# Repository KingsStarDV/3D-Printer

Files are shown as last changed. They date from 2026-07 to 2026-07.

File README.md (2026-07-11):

# 3D Printer

So by this time, really everyone knows what a 3d printer is...

### WHy I build it?

SO i built it for fun mainly..
i was out of ideas for normal project thus i started this..

This would definelty help not just me but many other people too, to make their own 3D printer !!

### How I build it and How can You Build this

## Requirement:

* ALuminium Extrusions of-
  * 2020 size- 380mm x2
  * 400mm x2
  * 2040 size- 150mm x2
  * 420mm x1
* Corner Brackets x4
* Inner Joints x6
* Sliding Nuts [as per your need, read the instructions first for this]
* Hot Glue
* Bolts
* Nuts
* 2020 Gantry Plates x4
* Derlin V wheels x16
* Nema 17 Stepper Motor x4
* Nema 17 Mounting bracket (L shaped) x4
* GT2 20 teeth Pulley x2
* 10mm timing belt (open)
* 10mm Idler Pulley x5
* 5mm to 8mm Coupler x1
* Lead Screw Tr8x2 x1
* Arduino Mega x1
* Ramps 1.4 x1
* Stepper Driver x4
* Power Supply (12v)
* Endstop swichtes
* Zip Ties
* MK8 hot end
* MK8 extruder
* hot bed

## Assembly

First Of all attach the two 150mm 2040 extrusions to the sides of the 420mm 2040 extrusion.



Secure it with inner joints on all 4 corners-



Next add the two 400mm 2020 extrusion of each side of the 150mm extrusion end- **[NOTE- In the image, i have used 2040 extrusion but i will change that later on due to some reasons.. so dont worry and add the 2020 extrusion]**



secure it with corner joints-



Now asseble your all 4 gantry plates with the wheels-



Now put one gantry plate along the 420mm extrusion (This will be the Y axis).



now take 2 gantry plates and fix them at end of a 380mm 2020 aluminium extrusion.. [Now you can use either HOT GLUE or SLiding joints to do this--- i will use hot glue]
And then put the 4th gantry plate along the 380mm aluminium extrusion you just fixed..



Now at one end of the Y axis (420mm extrusion 2040) fix a nema 17 mount (with either hot glue or sliding joints), and then hot glue the nema 17 motor to it-



This is not the indented way of using the nema 17 mount, but it works !!



then add a GT2 20 teeth pullay to the motor and also add a 10mm Idler pulley as shown in image below..For idler pulley support, you can use any hard- wooden block or hard carboard piece-



Now on the other end of the Y axis- with wooden blocks or cardboard make this and add two idler pulley to it-



Then take one nema 17 mount and cut it and modify it as-



This will go on the x axis along with the stepper motors (This can be hot glued or if possibles, screwed into the gantry plate)-



Next, we will require another custom part-



this can be made easily with cardboard(for the base) and old pens(for the cyclinderical part).

It has to be glued at the other end of the X axis-





Now at the top of the two 400mm 2020 extrusions add another 380mm extrusion..
and then fix another nema 17 mount (via either sliding nuts or hot glue)

Then fix the stepper motor to it-



Add a 5mm to 8mm coupler to it-



Now with help of another custom part make this (add the trapezoidal nut)--



he part must be fixed to the x axis.

Then take your extruder and fix it on the 400mm 2020 extrusion-



And make another custom part-



USe this to fix the hot end-



**If done every thing right, you should have -**



Now, just add your hot bed according to you--

I m doing it with a borosilicate glass...


Then Finally you can add the timing belts to the system...
It is kinda had to show how in fusion but you can refer to this great video by Superb Tech- https://youtu.be/N274UAxcQ4k?si=0m4HKMQeg1qyt50f
## Now for the electronics

Stack your ramps onto the arduino mega..
Then wire everything according to this diagram--



For this build though, I will not be using LCD and electronics fan..
Connect the stepper motor drivers onto the RAMPS and power the RAMPS with the 12V SMPS..

NOW--
Open the Marlin Firmware folder and inside find a Marlin folder and open it-
look for a Marlin.ino file in this folder. This is the main file to be uploaded to Arduino Mega..
But before that looks for a Configuaration.h file in that same folder and open it (open in notepad)
now look for
```
#define DEFAULT_AXIS_STEPS_PER_UNIT { 80, 80, 400, 93 }
```
&
```
#define X_BED_SIZE 220
#define Y_BED_SIZE 220
```
these must be adjusted by you for working of the printer..
if your build is just like mine, then you have to put these values-
```
#define DEFAULT_AXIS_STEPS_PER_UNIT { 80, 80, 1600, 93 }
```
&
```
#define X_BED_SIZE 200   
#define Y_BED_SIZE 150
```
or you can copy the "configuaration.h" from this repo.

and now you are all SET.

Just open the marlin.ino and upload the code to arduino mega...

Then open Printrun folder and open the exe file in it...

from here you can control and give print commands..

## Bill of Materials (BOM)

| # | Item | Description | Unit Price (Rs.) | Qty | Total (Rs.) | Link |
|---|---|---|---|-----|---|---|
| 1 | 2020 Aluminium Extrusion | Frame extrusion | 400 | 2 | 800 | [Buy](https://www.fastdep.in/product/tslot-2020/) |
| 2 | 2040 Aluminium Extrusion | Frame extrusion | 798 | 1 | 798 | [Buy](https://www.fastdep.in/product/tslot-2020/) |
| 3 | Corner Bracket | Frame joint | 30 | 4 | 120 | [Buy](https://www.fastdep.in/product/tslot-corner-bracket-20mm/) |
| 4 | Sliding Nut (pack of 10) | T-slot nuts | 145 | 1 | 145 | [Buy](https://www.fastdep.in/product/tnut-sliding-2020-m4/) |
| 5 | Gantry Plates | X-axis carriage plates | 350 | 4 | 1400 | [Buy](https://www.fastdep.in/product/openbuild-gantry-plate-20mm/) |
| 6 | V-Slot Wheels | Linear motion wheels | 95 | 16 | 1520 | [Buy](https://robocraze.com/products/openbuilds-v-slot-c-beam-wheel-kit) |
| 7 | NEMA 17 Mounting Bracket | Motor mount | 100 | 4 | 400 | [Buy](https://robocraze.com/products/mounting-l-bracket-of-nema-17-stepper-motor-for-3d-printer) |
| 8 | NEMA 17 Stepper Motor | X/Y/Z/E motors | 900 | 4 | 3600 | [Buy](https://robocraze.com/products/17hs8401s-nema17-stepper-motor-48mm) |
| 9 | Arduino Mega + RAMPS + 5x A4988 Combo | Mainboard + drivers | 2000 | 1 | 2000 | [Buy](https://robu.in/product/ramps-1-4-3d-printer-controllerarduino-mega2560-cable5pcs-4988-driver-heat-sink-kit/) |
| 10 | Lead Screw + Trapezoidal Nut (300mm) | Z-axis drive | 209 | 1 | 209 | [Buy](https://robu.in/product/300mm-trapezoidal-lead-screw-8mm-thread-2mm-pitch-lead-screw-copper-nut/) |
| 11 | MK8 Extruder | Filament extruder | 959 | 1 | 959 | [Buy](https://robocraze.com/products/mk8-extruder-for-3d-printers) |
| 12 | Hotend (J-Head Metal) | Hotend assembly | 372 | 1 | 372 | [Buy](https://robu.in/product/3d-printer-extruder-metal-j-head-hotend-reprap-makerbot-aluminium-assembled/) |
| 13 | End Stop Switches | Homing switches | 47 | 3 | 141 | [Buy](https://robocraze.com/products/endstop-switch-for-3d-printers-with-cable) |
| 14 | Timing Belt GT2 (Open) | X/Y belts | 91 | 2 | 182 | [Buy](https://robu.in/product/1m-gt2-width-6mm-black-open-timing-belt-for-3d-printer/) |
| 15 | GT2 Pulley (20 teeth) | Belt pulleys | 25 | 3 | 75 | [Buy](https://robu.in/product/1m-gt2-width-6mm-black-open-timing-belt-for-3d-printer/) |
| 16 | Idler Pulley | Belt tensioning | 100 | 5 | 500 | [Buy](https://www.fastdep.in/product/openbuild-smooth-idler-pulley/) |
| 17 | Hot Bed (MK2B) | Heated print bed | 525 | 1 | 525 | [Buy](https://roboticsdna.in/product/reprap-mk2b-3d-printers-dual-power-pcb-heat-bed/) |
| 18 | Dupont Connector Cable for NEMA 17 | Motor wiring | 45 | 3 | 135 | [Buy](https://robocraze.com/products/pure-copper-720mm-length-cable-with-dupont-connector-for-nema17-stepper-motor) |
| 19 | Power Supply (12V 15A SMPS) | PSU | 850 | 1 | 850 | [Buy](https://robocraze.com/products/12v-15a-power-supply-smps) |
| 20 | Miscellaneous (tape, wooden blocks, glue, wires, etc.) | Misc materials | 400 | 1 | 400 | — |
| | | | | **GRAND TOTAL** | **₹15,131** | |

So, this whole project would have not been possible if these video werent on youtube-

https://youtu.be/KCnO7spM0Vg?si=gGZklOslV_eG5gjN -By Superb Tech

https://youtu.be/oVOvzxD4o0Y?si=DU6qBV1OTGtgjgfD -By ELECOBOT

Thanks to THEM!!!!

My project is heavily inspired from-
I also got the Wiring Diagram from -
https://youtu.be/KCnO7spM0Vg?si=gGZklOslV_eG5gjN -By Superb Tech

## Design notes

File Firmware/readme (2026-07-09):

downlaod the printrun software from here-

https://www.youtube.com/redirect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

Download Marlin from here-

https://www.youtube.com/redirect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

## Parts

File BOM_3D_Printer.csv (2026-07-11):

Item | Description | Unit Price (Rs.) | Quantity | Total (Rs.) | Link
1 | 2020 Aluminium Extrusion | 400 | 2 | 800 | https://www.fastdep.in/product/tslot-2020/
2 | 2040 Aluminium Extrusion | 798 | 1 | 798 | https://www.fastdep.in/product/tslot-2020/
3 | Corner Bracket | 30 | 4 | 120 | https://www.fastdep.in/product/tslot-corner-bracket-20mm/
4 | Sliding Nut (pack of 10) | 145 | 1 | 145 | https://www.fastdep.in/product/tnut-sliding-2020-m4/
5 | Gantry Plates | 350 | 4 | 1400 | https://www.fastdep.in/product/openbuild-gantry-plate-20mm/
6 | V-Slot Wheels | 95 | 16 | 1520 | https://robocraze.com/products/openbuilds-v-slot-c-beam-wheel-kit
7 | NEMA 17 Mounting Bracket | 100 | 4 | 400 | https://robocraze.com/products/mounting-l-bracket-of-nema-17-stepper-motor-for-3d-printer
8 | NEMA 17 Stepper Motor | 900 | 4 | 3600 | https://robocraze.com/products/17hs8401s-nema17-stepper-motor-48mm
9 | Arduino Mega + RAMPS + 5x A4988 Combo | 2000 | 1 | 2000 | https://robu.in/product/ramps-1-4-3d-printer-controllerarduino-mega2560-cable5pcs-4988-driver-heat-sink-kit/
10 | Lead Screw + Trapezoidal Nut (300mm) | 209 | 1 | 209 | https://robu.in/product/300mm-trapezoidal-lead-screw-8mm-thread-2mm-pitch-lead-screw-copper-nut/
11 | MK8 Extruder | 959 | 1 | 959 | https://robocraze.com/products/mk8-extruder-for-3d-printers
12 | Hotend (J-Head Metal) | 372 | 1 | 372 | https://robu.in/product/3d-printer-extruder-metal-j-head-hotend-reprap-makerbot-aluminium-assembled/
13 | End Stop Switches | 47 | 3 | 141 | https://robocraze.com/products/endstop-switch-for-3d-printers-with-cable
14 | Timing Belt GT2 (Open) | 91 | 2 | 182 | https://robu.in/product/1m-gt2-width-6mm-black-open-timing-belt-for-3d-printer/
15 | GT2 Pulley (20 teeth) | 25 | 3 | 75 | https://robu.in/product/1m-gt2-width-6mm-black-open-timing-belt-for-3d-printer/
16 | Idler Pulley | 100 | 5 | 500 | https://www.fastdep.in/product/openbuild-smooth-idler-pulley/
17 | Hot Bed (MK2B) | 525 | 1 | 525 | https://roboticsdna.in/product/reprap-mk2b-3d-printers-dual-power-pcb-heat-bed/
18 | Dupont Connector Cable for NEMA 17 | 45 | 3 | 135 | https://robocraze.com/products/pure-copper-720mm-length-cable-with-dupont-connector-for-nema17-stepper-motor
19 | Power Supply (12V 15A SMPS) | 850 | 1 | 850 | https://robocraze.com/products/12v-15a-power-supply-smps
20 | Miscellaneous (tape | wooden blocks | glue | wires | etc.) | 400 | 1 | 400
 |  |  | GRAND TOTAL | 15131

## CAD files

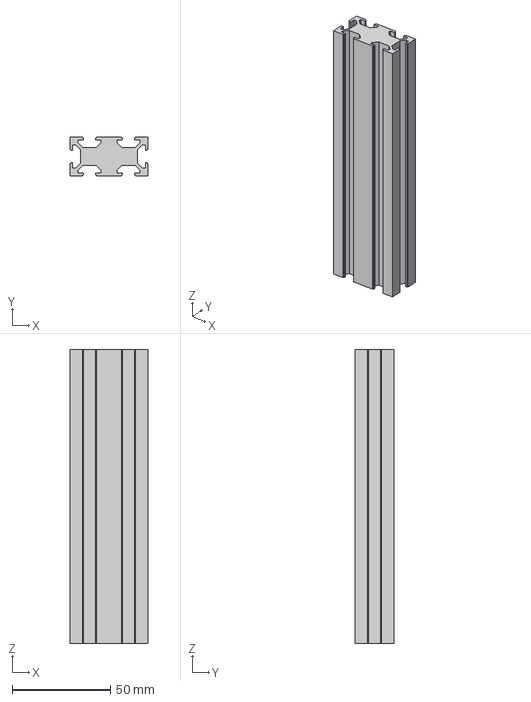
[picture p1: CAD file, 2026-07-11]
CAD/STEP Files/150mm 2040 Aluminium Extrusion.step
40.0 x 20.0 x 150.0 mm

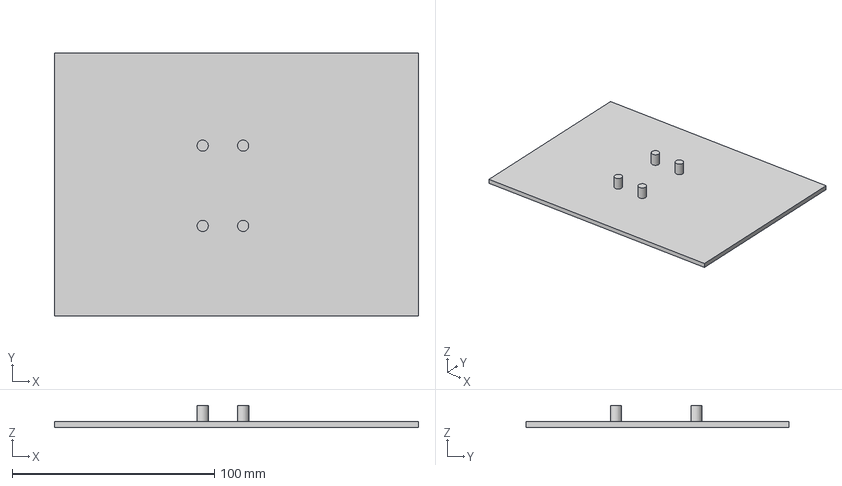
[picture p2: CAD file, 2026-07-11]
CAD/STEP Files/Y carriage.step
180.0 x 130.0 x 11.0 mm

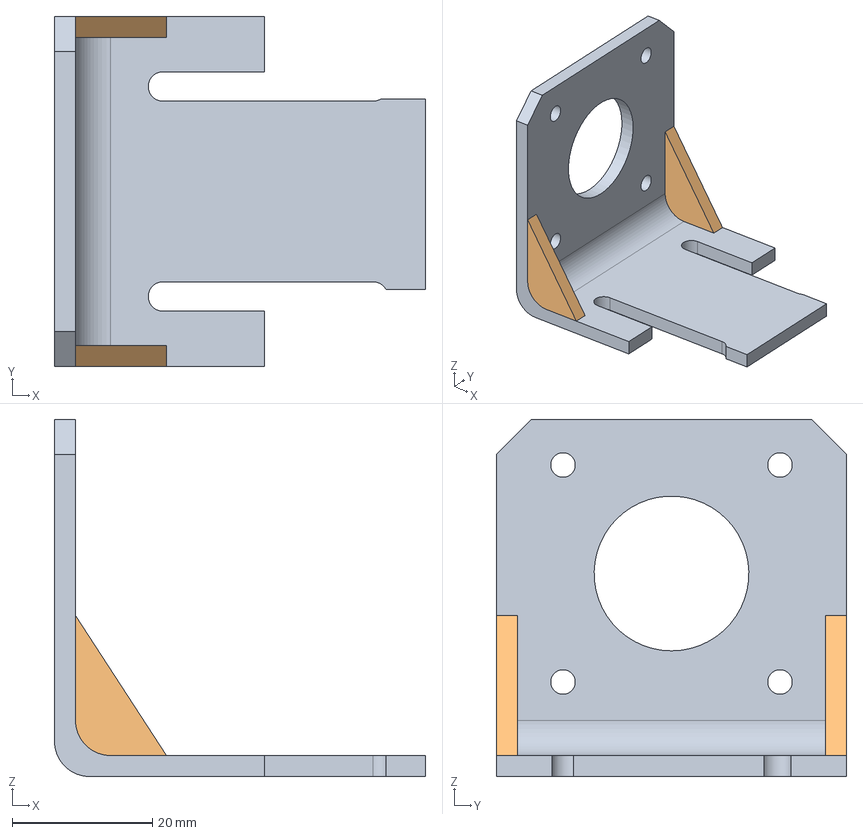
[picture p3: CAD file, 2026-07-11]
CAD/STEP Files/S-Nema17 Mount.step
53.0 x 50.0 x 51.0 mm

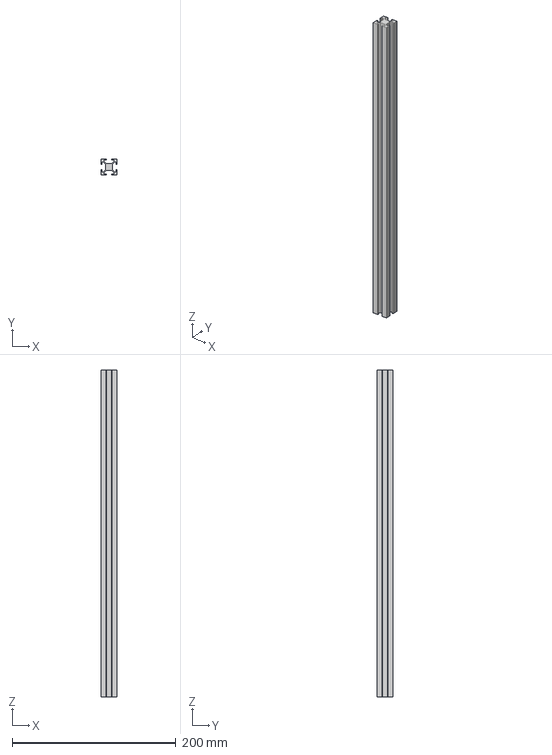
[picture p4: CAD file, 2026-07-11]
CAD/STEP Files/400mm 2020 Aluminium Extrusion.step
20.0 x 20.0 x 400.0 mm

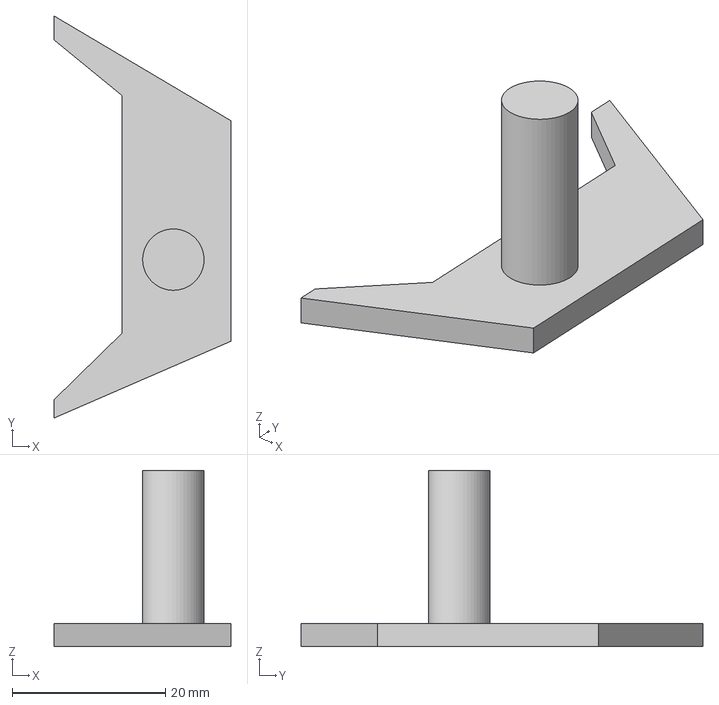
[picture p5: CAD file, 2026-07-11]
CAD/STEP Files/Support X axis idlers.step
23.0 x 52.4 x 23.0 mm

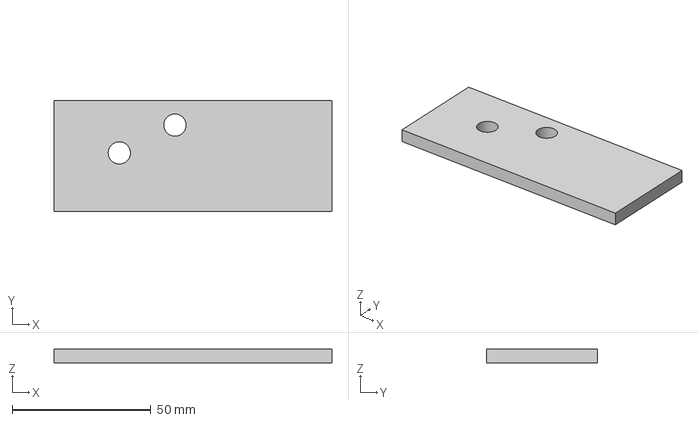
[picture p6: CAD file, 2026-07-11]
CAD/STEP Files/Y axis Idler Pulley Plate support.step
100.0 x 40.0 x 5.00 mm

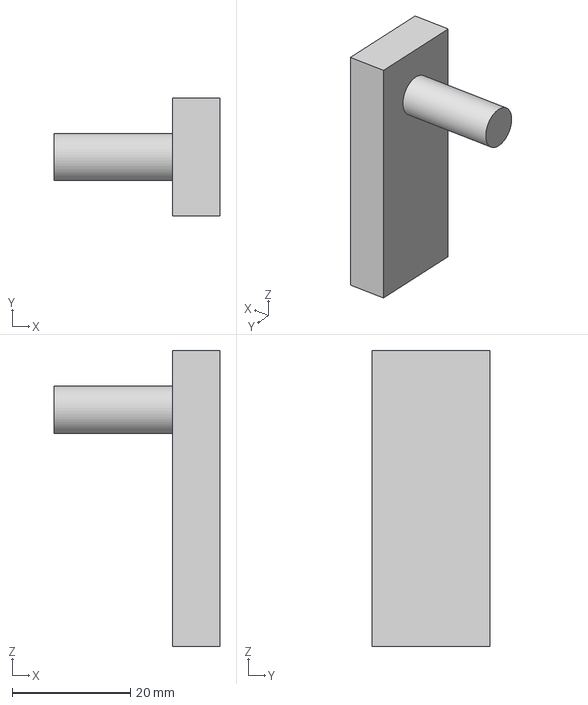
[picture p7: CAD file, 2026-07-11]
CAD/STEP Files/Y axis Idler pulley suppport.step
28.0 x 20.0 x 50.0 mm

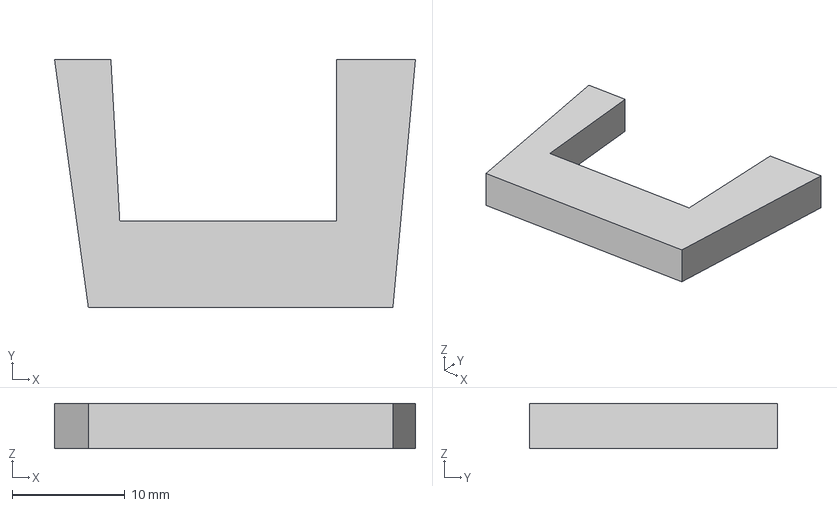
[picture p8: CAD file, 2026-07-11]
CAD/STEP Files/hot end suppport.step
32.0 x 22.0 x 4.00 mm

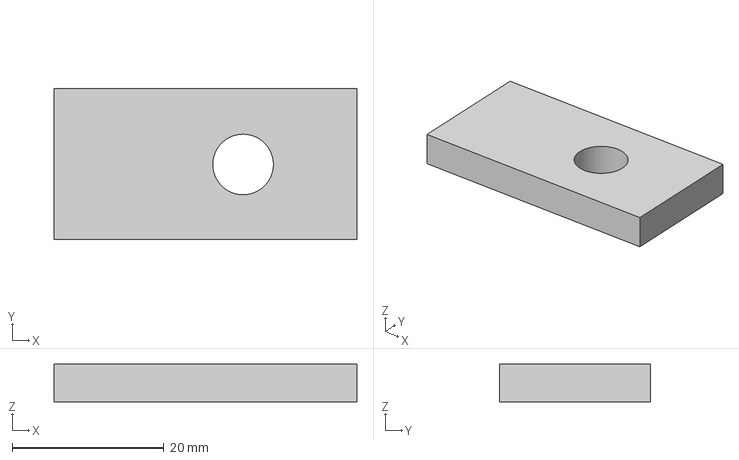
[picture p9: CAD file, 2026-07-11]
CAD/STEP Files/LeadScrew Support.step
40.0 x 20.0 x 5.00 mm

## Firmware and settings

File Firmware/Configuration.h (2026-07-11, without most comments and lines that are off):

#define CONFIGURATION_H
#define CONFIGURATION_H_VERSION 010109
#define STRING_CONFIG_H_AUTHOR "(none, default config)" // Who made the changes.
#define SHOW_BOOTSCREEN
#define STRING_SPLASH_LINE1 SHORT_BUILD_VERSION // will be shown during bootup in line 1
#define STRING_SPLASH_LINE2 WEBSITE_URL         // will be shown during bootup in line 2
#define SERIAL_PORT 0
#define BAUDRATE 250000
  #define MOTHERBOARD BOARD_RAMPS_14_EFB
#define EXTRUDERS 1
#define DEFAULT_NOMINAL_FILAMENT_DIA 3.0
#define POWER_SUPPLY 0
#define TEMP_SENSOR_0 1
#define TEMP_SENSOR_1 0
#define TEMP_SENSOR_2 0
#define TEMP_SENSOR_3 0
#define TEMP_SENSOR_4 0
#define TEMP_SENSOR_BED 0
#define TEMP_SENSOR_CHAMBER 0
#define DUMMY_THERMISTOR_998_VALUE 25
#define DUMMY_THERMISTOR_999_VALUE 100
#define MAX_REDUNDANT_TEMP_SENSOR_DIFF 10
#define TEMP_RESIDENCY_TIME 10  // (seconds)
#define TEMP_HYSTERESIS 3       // (degC) range of +/- temperatures considered "close" to the target one
#define TEMP_WINDOW     1       // (degC) Window around target to start the residency timer x degC early.
#define TEMP_BED_RESIDENCY_TIME 10  // (seconds)
#define TEMP_BED_HYSTERESIS 3       // (degC) range of +/- temperatures considered "close" to the target one
#define TEMP_BED_WINDOW     1       // (degC) Window around target to start the residency timer x degC early.
#define HEATER_0_MINTEMP 5
#define HEATER_1_MINTEMP 5
#define HEATER_2_MINTEMP 5
#define HEATER_3_MINTEMP 5
#define HEATER_4_MINTEMP 5
#define BED_MINTEMP 5
#define HEATER_0_MAXTEMP 275
#define HEATER_1_MAXTEMP 275
#define HEATER_2_MAXTEMP 275
#define HEATER_3_MAXTEMP 275
#define HEATER_4_MAXTEMP 275
#define BED_MAXTEMP 150
#define PIDTEMP
#define BANG_MAX 255     // Limits current to nozzle while in bang-bang mode; 255=full current
#define PID_MAX BANG_MAX // Limits current to nozzle while PID is active (see PID_FUNCTIONAL_RANGE below); 255=full current
#define PID_K1 0.95      // Smoothing factor within any PID loop
  #define PID_FUNCTIONAL_RANGE 10 // If the temperature difference between the target temperature and the actual temperature
  #define DEFAULT_Kp 22.2
  #define DEFAULT_Ki 1.08
  #define DEFAULT_Kd 114
#define MAX_BED_POWER 255 // limits duty cycle to bed; 255=full current
#define PREVENT_COLD_EXTRUSION
#define EXTRUDE_MINTEMP 170
#define PREVENT_LENGTHY_EXTRUDE
#define EXTRUDE_MAXLENGTH 200
#define THERMAL_PROTECTION_HOTENDS // Enable thermal protection for all extruders
#define THERMAL_PROTECTION_BED     // Enable thermal protection for the heated bed
#define USE_XMIN_PLUG
#define USE_YMIN_PLUG
#define USE_ZMIN_PLUG
#define ENDSTOPPULLUPS
#define X_MIN_ENDSTOP_INVERTING false // set to true to invert the logic of the endstop.
#define Y_MIN_ENDSTOP_INVERTING false // set to true to invert the logic of the endstop.
#define Z_MIN_ENDSTOP_INVERTING false // set to true to invert the logic of the endstop.
#define X_MAX_ENDSTOP_INVERTING false // set to true to invert the logic of the endstop.
#define Y_MAX_ENDSTOP_INVERTING false // set to true to invert the logic of the endstop.
#define Z_MAX_ENDSTOP_INVERTING false // set to true to invert the logic of the endstop.
#define Z_MIN_PROBE_ENDSTOP_INVERTING false // set to true to invert the logic of the probe.
#define DEFAULT_AXIS_STEPS_PER_UNIT { 80, 80, 1600, 93 }
#define DEFAULT_MAX_FEEDRATE          { 300, 300, 5, 25 }
#define DEFAULT_MAX_ACCELERATION      { 3000, 3000, 100, 10000 }
#define DEFAULT_ACCELERATION          3000    // X, Y, Z and E acceleration for printing moves
#define DEFAULT_RETRACT_ACCELERATION  3000    // E acceleration for retracts
#define DEFAULT_TRAVEL_ACCELERATION   3000    // X, Y, Z acceleration for travel (non printing) moves
#define DEFAULT_XJERK                 10.0
#define DEFAULT_YJERK                 10.0
#define DEFAULT_ZJERK                  0.3
#define DEFAULT_EJERK                  5.0
#define Z_MIN_PROBE_USES_Z_MIN_ENDSTOP_PIN
#define X_PROBE_OFFSET_FROM_EXTRUDER 10  // X offset: -left  +right  [of the nozzle]
#define Y_PROBE_OFFSET_FROM_EXTRUDER 10  // Y offset: -front +behind [the nozzle]
#define Z_PROBE_OFFSET_FROM_EXTRUDER 0   // Z offset: -below +above  [the nozzle]
#define MIN_PROBE_EDGE 10
#define XY_PROBE_SPEED 8000
#define Z_PROBE_SPEED_FAST HOMING_FEEDRATE_Z
#define Z_PROBE_SPEED_SLOW (Z_PROBE_SPEED_FAST / 2)
#define Z_CLEARANCE_DEPLOY_PROBE   10 // Z Clearance for Deploy/Stow
#define Z_CLEARANCE_BETWEEN_PROBES  5 // Z Clearance between probe points
#define Z_CLEARANCE_MULTI_PROBE     5 // Z Clearance between multiple probes
#define Z_PROBE_LOW_POINT          -2 // Farthest distance below the trigger-point to go before stopping
#define Z_PROBE_OFFSET_RANGE_MIN -20
#define Z_PROBE_OFFSET_RANGE_MAX 20
#define X_ENABLE_ON 0
#define Y_ENABLE_ON 0
#define Z_ENABLE_ON 0
#define E_ENABLE_ON 0 // For all extruders
#define DISABLE_X false
#define DISABLE_Y false
#define DISABLE_Z false
#define DISABLE_E false // For all extruders
#define DISABLE_INACTIVE_EXTRUDER true // Keep only the active extruder enabled.
#define INVERT_X_DIR false
#define INVERT_Y_DIR true
#define INVERT_Z_DIR false
#define INVERT_E0_DIR false
#define INVERT_E1_DIR false
#define INVERT_E2_DIR false
#define INVERT_E3_DIR false
#define INVERT_E4_DIR false
#define X_HOME_DIR -1
#define Y_HOME_DIR -1
#define Z_HOME_DIR -1
#define X_BED_SIZE 200
#define Y_BED_SIZE 150
#define X_MIN_POS 0
#define Y_MIN_POS 0
#define Z_MIN_POS 0
#define X_MAX_POS X_BED_SIZE
#define Y_MAX_POS Y_BED_SIZE
#define Z_MAX_POS 200
#define MIN_SOFTWARE_ENDSTOPS
  #define MIN_SOFTWARE_ENDSTOP_X
  #define MIN_SOFTWARE_ENDSTOP_Y
  #define MIN_SOFTWARE_ENDSTOP_Z
#define MAX_SOFTWARE_ENDSTOPS
  #define MAX_SOFTWARE_ENDSTOP_X
  #define MAX_SOFTWARE_ENDSTOP_Y
  #define MAX_SOFTWARE_ENDSTOP_Z
#define HOMING_FEEDRATE_XY (50*60)
#define HOMING_FEEDRATE_Z  (4*60)
#define EEPROM_CHITCHAT   // Give feedback on EEPROM commands. Disable to save PROGMEM.
#define HOST_KEEPALIVE_FEATURE        // Disable this if your host doesn't like keepalive messages
#define DEFAULT_KEEPALIVE_INTERVAL 2  // Number of seconds between "busy" messages. Set with M113.
#define BUSY_WHILE_HEATING            // Some hosts require "busy" messages even during heating
#define PREHEAT_1_TEMP_HOTEND 180
#define PREHEAT_1_TEMP_BED     70
#define PREHEAT_1_FAN_SPEED     0 // Value from 0 to 255
#define PREHEAT_2_TEMP_HOTEND 240
#define PREHEAT_2_TEMP_BED    110
#define PREHEAT_2_FAN_SPEED     0 // Value from 0 to 255
#define PRINTJOB_TIMER_AUTOSTART
#define LCD_LANGUAGE en
#define DISPLAY_CHARSET_HD44780 JAPANESE
#define SOFT_PWM_SCALE 0
#define SERVO_DELAY { 300 }

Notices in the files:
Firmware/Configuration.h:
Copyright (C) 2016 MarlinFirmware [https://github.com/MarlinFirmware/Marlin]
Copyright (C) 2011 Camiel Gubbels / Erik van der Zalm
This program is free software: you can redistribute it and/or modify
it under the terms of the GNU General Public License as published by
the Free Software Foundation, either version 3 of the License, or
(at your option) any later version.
